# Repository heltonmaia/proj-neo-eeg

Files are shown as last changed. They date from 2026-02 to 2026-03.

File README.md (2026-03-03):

# Neo-EEG Project

Open-source 8-channel EEG acquisition system based on ADS1299 and ESP32.

## Hardware

| Component | Description |
|---|---|
| MCU | ESP32 |
| ADC | ADS1299 (8 channels, 24-bit) |
| Connection | WiFi (UDP) or Bluetooth SPP |
| PCB | PotyEEG v9 |

## Project Structure

```
proj-neo-eeg/
├── docs/
│   ├── datasheets/             # ADS1299 datasheets
│   └── troubleshooting.md      # Troubleshooting guide
│
├── firmware/
│   ├── esp32-wifi/             # ESP32 WiFi firmware
│   │   └── EEG_Poty_ESP32_V10/
│   └── libraries/              # Arduino dependencies
│
├── hardware/
│   └── pcb/
│       └── PotyEEG_v9/         # Eagle PCB files
│
├── software-web/               # Web application (recommended)
│   ├── run.py                  # Cross-platform launcher
│   ├── backend/                # FastAPI server
│   └── frontend/               # React application
│
└── software-processing/        # OpenBCI GUI (legacy)
    └── openbci-gui/
```

## Quick Start (Web Application)

### 1. Flash Firmware

1. Open Arduino IDE
2. Install ESP32 board support
3. Open `firmware/esp32-wifi/EEG_Poty_ESP32_V10/EEG_Poty_ESP32_V10.ino`
4. Select board: ESP32 Dev Module
5. Upload

### 2. Connect to ESP32 WiFi

- **SSID:** `Potyplex-EEG`
- **Password:** `eeg12345`

### 3. Run Web Application

```bash
cd software-web
python run.py
```

Select option `1` to start all services, then open http://localhost:3000

### 4. Use

1. Click **Start** to begin EEG streaming
2. Click **Start Camera** to enable video (optional)
3. Select **Signals** and/or **Video** checkboxes
4. Click **REC** to record

## Features

- Real-time 8-channel EEG visualization
- USB camera streaming
- Recording to CSV (signals) and MP4 (video)
- Offline recording playback
- Dark/Light theme
- Channel selection and zoom controls
- Cross-platform (Linux, Windows, macOS)

## Firmware

The ESP32 firmware streams OpenBCI-compatible packets:

- **Protocol**: OpenBCI binary format (33 bytes)
- **Sample Rate**: 250 Hz
- **Channels**: 8 (ADS1299)
- **Transport**: UDP over WiFi

## Requirements

### Firmware
- Arduino IDE 2.x
- ESP32 Board Support

### Web Application
- Python 3.8+
- Node.js 18+
- OpenCV (for camera)

## License

MIT License

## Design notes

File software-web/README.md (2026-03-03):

# Potyplex EEG - Web Application

Real-time EEG visualization and recording using FastAPI + React.

## Architecture

```
┌─────────────┐     UDP      ┌─────────────┐   WebSocket   ┌─────────────┐
│   ESP32     │─────────────►│   Backend   │──────────────►│  Frontend   │
│  (WiFi AP)  │   12345      │  (FastAPI)  │    8000       │   (React)   │
└─────────────┘              └─────────────┘               └─────────────┘
                                   │
                              ┌────┴────┐
                              │ Camera  │
                              │ (USB)   │
                              └─────────┘
```

## Features

- Real-time 8-channel EEG visualization
- USB camera streaming
- Recording (signals, video, or both)
- Offline recording playback
- Dark/Light theme
- Cross-platform (Linux, Windows, macOS)

## Requirements

- Python 3.8+
- Node.js 18+
- OpenCV (for camera support)
- Modern browser (Chrome, Firefox, Edge)
- UV (optional, recommended for faster dependency management)

## Quick Start

```bash
python run.py
```

This opens an interactive menu to start/stop services, run tests, and more.

**Environment Support:**
- Automatically detects existing UV environments
- Falls back to standard Python venv if UV is not available
- Saves environment configuration in `.env.local.json`

## Manual Start

```bash
# Terminal 1 - Backend (with UV)
cd backend
uv pip install -r requirements.txt
uvicorn server:app --reload --host 0.0.0.0 --port 8000

# Terminal 1 - Backend (without UV)
cd backend
pip install -r requirements.txt
uvicorn server:app --reload --host 0.0.0.0 --port 8000

# Terminal 2 - Frontend
cd frontend
npm install
npm run dev
```

## Usage

1. Connect to ESP32 WiFi: `Potyplex-EEG` (password: `eeg12345`)
2. Run `python run.py` and select "Start All"
3. Open http://localhost:3000
4. Click **Start** to begin EEG streaming
5. Click **Start Camera** to enable video (optional)
6. Select **Signals** and/or **Video** checkboxes
7. Click **REC** to record

## Menu Options

| Key | Action |
|-----|---|
| 1 | Start All (backend + frontend) |
| 2 | Stop All |
| 3 | Restart All |
| 4 | Start Backend only |
| 5 | Stop Backend |
| 6 | Stop Frontend |
| 7 | View Backend Logs |
| 8 | View Frontend Logs |
| 9 | Install Dependencies |
| t | Run Tests |
| s | Setup Python Environment |
| k | Kill Stale Processes |
| 0 | Exit |

## API Endpoints

| Method | Endpoint | Description |
|---|---|---|
| POST | `/start` | Start EEG streaming |
| POST | `/stop` | Stop EEG streaming |
| POST | `/record/start` | Start recording |
| POST | `/record/stop` | Stop recording |
| GET | `/recordings` | List recordings |
| GET | `/recordings/{id}` | Get recording data |
| GET | `/recordings/{id}/video` | Stream video (MP4) |
| DELETE | `/recordings/{id}` | Delete recording |
| GET | `/cameras` | List cameras |
| POST | `/camera/start` | Start camera |
| POST | `/camera/stop` | Stop camera |
| WS | `/ws` | EEG data stream |
| WS | `/ws/camera` | Camera stream |

## Project Structure

```
software-web/
├── run.py             # Cross-platform service manager
├── backend/
│   ├── server.py      # FastAPI server
│   ├── test_server.py # Backend tests (20 tests)
│   ├── requirements.txt
│   └── recordings/    # Saved recordings
├── frontend/
│   ├── src/
│   │   ├── App.jsx
│   │   ├── App.css
│   │   └── components/
│   │       ├── EEGChart.jsx
│   │       ├── CameraPanel.jsx
│   │       └── RecordingsTab.jsx
│   ├── package.json
│   └── vite.config.js
└── README.md
```

## Recording Format

Recordings are stored in `backend/recordings/YYYYMMDD_HHMMSS/`:

- `metadata.json` - Session info (duration, channels, etc.)
- `data.csv` - EEG signals (if recorded)
- `video.mp4` - Camera video (if recorded)

## Testing

Run backend tests:
```bash
python run.py  # then press 't'
```

Or directly:
```bash
cd backend
pytest test_server.py -v
```

## Troubleshooting

**Backend not receiving data:**
- Verify connection to ESP32 WiFi
- Check ESP32 LED is blinking

**Camera not working:**
- Check USB camera is connected
- Verify OpenCV is installed: `pip install opencv-python`

**Services won't start:**
- Press 'k' to kill stale processes
- Check logs with options 7/8

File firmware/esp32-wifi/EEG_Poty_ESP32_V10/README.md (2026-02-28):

# ESP32 WiFi Firmware (Access Point Mode)

Versão modificada do firmware para usar WiFi UDP ao invés de Bluetooth SPP. O ESP32 cria sua própria rede WiFi (Access Point).

## Arquitetura

```
                    ┌──────────────────────┐
                    │   Potyplex EEG       │
[Computador] ◄─────►│   Access Point       │
     ou             │                      │
[Celular]    ◄─UDP─►│   SSID: Potyplex-EEG │
                    │   IP: 192.168.4.1    │
                    │   Port: 12345        │
                    └──────────────────────┘
```

**Conecte diretamente no EEG - não precisa de roteador!**

## Configuração Padrão

| Parâmetro | Valor |
|---|---|
| SSID | `Potyplex-EEG` |
| Senha | `eeg12345` |
| IP do ESP32 | `192.168.4.1` |
| Porta UDP | `12345` |

---

## Instalação

### 1. Instalar Bibliotecas (Arduino IDE)

Vá em **Sketch → Include Library → Manage Libraries** e instale:
- `Adafruit MPU6050`
- `Adafruit BusIO`
- `Adafruit Unified Sensor`

### 2. Configurar (opcional)

Edite `EEG_Poty_ESP32_Library_Definitions.h`:

```c
#define AP_SSID     "Potyplex-EEG"    // Nome da rede
#define AP_PASSWORD "eeg12345"         // Senha (min 8 chars)
#define AP_CHANNEL  1                  // Canal WiFi (1-13)
#define UDP_PORT    12345              // Porta UDP
```

### 3. Compilar e Upload

1. Abra Arduino IDE
2. Selecione placa: **ESP32 Dev Module**
3. Abra `EEG_Poty_ESP32_V10.ino`
4. Clique em Upload

### 4. Verificar

Abra Serial Monitor (115200 baud):

```
===========================================
  Potyplex EEG - WiFi Access Point Mode
===========================================
Creating network: Potyplex-EEG
[OK] Access Point started!
SSID: Potyplex-EEG
Password: eeg12345
ESP32 IP: 192.168.4.1
UDP Port: 12345
[OK] UDP server started
===========================================
  1. Connect to WiFi: Potyplex-EEG
  2. Send 'b' to 192.168.4.1:12345
===========================================
```

---

## Conectando e Recebendo Dados

### Linux - Teste Rápido

```bash
# 1. Conecte no WiFi "Potyplex-EEG" (senha: eeg12345)

# 2. Enviar comando e receber dados
nc -u 192.168.4.1 12345
# Digite 'b' + Enter para iniciar streaming
# Digite 's' + Enter para parar
```

### Celular

Use um app UDP (ex: "UDP Terminal" no Android):
1. Conecte no WiFi `Potyplex-EEG`
2. Configure IP: `192.168.4.1`, Port: `12345`
3. Envie `b` para iniciar

### Python - Cliente Completo

```python
#!/usr/bin/env python3
"""
Cliente para Potyplex EEG WiFi
"""
import socket

ESP32_IP = "192.168.4.1"
UDP_PORT = 12345

# Criar socket UDP
sock = socket.socket(socket.AF_INET, socket.SOCK_DGRAM)
sock.settimeout(5.0)
sock.bind(('0.0.0.0', 0))  # Bind em porta aleatória

# Iniciar streaming
sock.sendto(b'b', (ESP32_IP, UDP_PORT))
print("Streaming iniciado!")

# Receber dados
while True:
    try:
        data, addr = sock.recvfrom(33)

        if len(data) == 33 and data[0] == 0xA0 and data[32] == 0xC0:
            sample_num = data[1]

            # Extrair 8 canais (24 bits cada, signed)
            channels = []
            for ch in range(8):
                offset = 2 + ch * 3
                raw = (data[offset] << 16) | (data[offset+1] << 8) | data[offset+2]
                if raw & 0x800000:  # Negativo (complemento de 2)
                    raw -= 0x1000000
                channels.append(raw)

            print(f"Sample {sample_num:3d}: CH1={channels[0]:8d} CH2={channels[1]:8d}")

    except socket.timeout:
        print("Timeout")
        break
    except KeyboardInterrupt:
        sock.sendto(b's', (ESP32_IP, UDP_PORT))
        print("Streaming parado")
        break

sock.close()
```

---

## Protocolo de Dados

Cada pacote tem **33 bytes**:

| Offset | Tamanho | Descrição |
|---|---|---|
| 0 | 1 | Header: `0xA0` |
| 1 | 1 | Contador (0-255) |
| 2-25 | 24 | 8 canais EEG (3 bytes cada, 24-bit signed) |
| 26-31 | 6 | Acelerômetro (3 eixos, 2 bytes cada) |
| 32 | 1 | Footer: `0xC0` |

**Taxa:** 250 amostras/segundo

---

## Comandos OpenBCI

| Comando | Descrição |
|---|---|
| `b` | Iniciar streaming |
| `s` | Parar streaming |
| `v` | Soft reset (mostra info) |
| `?` | Query registradores |
| `d` | Configurações default |
| `1-8` | Desligar canal 1-8 |
| `!@#$%^&*` | Ligar canal 1-8 |

---

## LED Status

| Padrão | Significado |
|---|---|
| 3 piscadas rápidas | AP iniciado OK |
| LED fixo | Erro ao criar AP |
| Piscando durante streaming | Enviando dados |

---

## Arquivos

| Arquivo | Descrição |
|---|---|
| `EEG_Poty_ESP32_V10.ino` | Sketch principal |
| `EEG_Poty_ESP32_Library_Definitions.h` | Configurações WiFi/hardware |
| `EEG_Poty_ESP32_Library.h` | Header da biblioteca |
| `EEG_Poty_ESP32_Library.cpp` | Implementação |

---

## Troubleshooting

### Não encontra a rede WiFi
- Verifique Serial Monitor para erros
- Tente mudar `AP_CHANNEL` para outro canal (1-13)

### Não recebe dados
- Verifique se está conectado na rede `Potyplex-EEG`
- Confirme IP `192.168.4.1` e porta `12345`
- Envie `b` para iniciar streaming

### Cliente desconecta
- Timeout padrão é 30 segundos sem comandos
- Envie qualquer comando como keepalive
- Ou aumente `CLIENT_TIMEOUT_MS` em `_Definitions.h`

---

## Referências

- [ESP32 WiFi API](https://docs.espressif.com/projects/esp-idf/en/latest/esp32/api-reference/network/esp_wifi.html)
- [OpenBCI Protocol](https://docs.openbci.com/Cyton/CytonSDK/)

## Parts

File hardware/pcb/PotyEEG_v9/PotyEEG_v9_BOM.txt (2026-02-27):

Partlist exported from D:/Users/WinU31/Documents/Projects/PotyEEG/Project/Hardware/PotyEEG_v9.sch at 29/10/2021 20:17

Part Value                                                              Device                                                             Package                           Description                                                   
C1   0.1uF                                                              C-EUC0805K                                                         C0805K                            CAPACITOR, European symbol                                    
C2   10uF                                                               C-EUC0805K                                                         C0805K                            CAPACITOR, European symbol                                    
C3   10uF                                                               C-EUC0805K                                                         C0805K                            CAPACITOR, European symbol                                    
C4   .1uF                                                               C-EUC0805K                                                         C0805K                            CAPACITOR, European symbol                                    
C5   1uF                                                                C-EUC0805K                                                         C0805K                            CAPACITOR, European symbol                                    
C6   100uF                                                              C-EUC0805K                                                         C0805K                            CAPACITOR, European symbol                                    
C7   1uF                                                                C-EUC0805K                                                         C0805K                            CAPACITOR, European symbol                                    
C8   2.2uF                                                              C-EUC0805K                                                         C0805K                            CAPACITOR, European symbol                                    
C9   2.2uF                                                              C-EUC0805K                                                         C0805K                            CAPACITOR, European symbol                                    
C10  10uF                                                               C-EUC0805K                                                         C0805K                            CAPACITOR, European symbol                                    
C11  10uF                                                               C-EUC0805K                                                         C0805K                            CAPACITOR, European symbol                                    
C12  0.01uF                                                             C-EUC0805K                                                         C0805K                            CAPACITOR, European symbol                                    
C13  2.2uF                                                              C-EUC0805K                                                         C0805K                            CAPACITOR, European symbol                                    
C14  10uF                                                               C-EUC0805K                                                         C0805K                            CAPACITOR, European symbol                                    
C15  2.2uF                                                              C-EUC0805K                                                         C0805K                            CAPACITOR, European symbol                                    
C16  10uF                                                               C-EUC0805K                                                         C0805K                            CAPACITOR, European symbol                                    
C17  10uF                                                               C-EUC0603                                                          C0603                             CAPACITOR, European symbol                                    
C18  10uF                                                               C-EUC0603                                                          C0603                             CAPACITOR, European symbol                                    
C19  10uF                                                               C-EUC0805K                                                         C0805K                            CAPACITOR, European symbol                                    
C20  10uF                                                               C-EUC0805K                                                         C0805K                            CAPACITOR, European symbol                                    
C21  10uF                                                               C-EUC0805K                                                         C0805K                            CAPACITOR, European symbol                                    
C25  1000pF                                                             C-EUC0603                                                          C0603                             CAPACITOR, European symbol                                    
C26  1000pF                                                             C-EUC0603                                                          C0603                             CAPACITOR, European symbol                                    
C27  1000pF                                                             C-EUC0603                                                          C0603                             CAPACITOR, European symbol                                    
C28  1000pF                                                             C-EUC0603                                                          C0603                             CAPACITOR, European symbol                                    
C29  1000pF                                                             C-EUC0603                                                          C0603                             CAPACITOR, European symbol                                    
C30  1000pF                                                             C-EUC0603                                                          C0603                             CAPACITOR, European symbol                                    
C31  1000pF                                                             C-EUC0603                                                          C0603                             CAPACITOR, European symbol                                    
C32  1000pF                                                             C-EUC0603                                                          C0603                             CAPACITOR, European symbol                                    
LED1                                                                    LEDSML0805                                                         SML0805                           LED                                                           
LED2                                                                    LEDSML0805                                                         SML0805                           LED                                                           
R1   2,2K                                                               R-EU_R0603                                                         R0603                             RESISTOR, European symbol                                     
R2   2,2K                                                               R-EU_R0603                                                         R0603                             RESISTOR, European symbol                                     
R3   2,2K                                                               R-EU_R0603                                                         R0603                             RESISTOR, European symbol                                     
R9   2,2K                                                               R-EU_R0603                                                         R0603                             RESISTOR, European symbol                                     
R10  2,2K                                                               R-EU_R0603                                                         R0603                             RESISTOR, European symbol                                     
R11  2,2K                                                               R-EU_R0603                                                         R0603                             RESISTOR, European symbol                                     
R12  2,2K                                                               R-EU_R0603                                                         R0603                             RESISTOR, European symbol                                     
R13  2,2K                                                               R-EU_R0603                                                         R0603                             RESISTOR, European symbol                                     
R14  2,2K                                                               R-EU_R0603                                                         R0603                             RESISTOR, European symbol                                     
R15  2,2K                                                               R-EU_R0603                                                         R0603                             RESISTOR, European symbol                                     
R16  2,2K                                                               R-EU_R0603                                                         R0603                             RESISTOR, European symbol                                     
S1   SKHMPSE010                                                         SKHMPSE010                                                         SKHMPXE010                        6.2 X 6.5mm TACT Switch (SMD)                                 
U1   ADS1299IPAG                                                        ADS1299IPAG                                                        PAG64_TEX                                                                                       
U2   MICROCHIP_MCP1754T-3302E-OTMICROCHIP_MCP1754T-3302E-OT_0_1         MICROCHIP_MCP1754T-3302E-OTMICROCHIP_MCP1754T-3302E-OT_0_1         MICROCHIP_MCP1754T-3302E-OT_1     MCHP-MCP1754-SOT-23-5                                         
U3   TEXAS_INSTRUMENTS_LM2664M6-NOPBTEXAS_INSTRUMENTS_LM2664M6-NOPB_0_2 TEXAS_INSTRUMENTS_LM2664M6-NOPBTEXAS_INSTRUMENTS_LM2664M6-NOPB_0_2 TEXAS_INSTRUMENTS_LM2664M6-NOPB_2 PM-CHP-LM2664M6-6                                             
U4   TPS72325DBVTDBV5_TEX-M                                             TPS72325DBVTDBV5_TEX-M                                             DBV5_TEX-M                                                                                      
U5   TLV70012DDCRDDC5-M                                                 TLV70012DDCRDDC5-M                                                 DDC5-M                                                                                          
U6   DFR0478                                                            DFR0478                                                            FIREBEETLE_ESP32                  Development Boards & Kits - Wireless FireBeetle ESP32 IOT MCU 
U7   TPD4E1B06DRLR                                                      TPD4E1B06DRLR                                                      SOP50P160X60-6N                   Bidirectional Quad-Channel High-Speed ESD Protection Device   
U8   TPD4E1B06DRLR                                                      TPD4E1B06DRLR                                                      SOP50P160X60-6N                   Bidirectional Quad-Channel High-Speed ESD Protection Device   
X3   53261-14                                                           53261-14                                                           53261-14                          CONNECTOR

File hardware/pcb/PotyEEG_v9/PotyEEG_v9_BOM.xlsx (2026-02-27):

Part | Value | Device | Package | Description | Price
C1 | 0.1uF | C-EUC0805K | C0805K | CAPACITOR, | 0.4 | https://br.mouser.com/ProductDetail/Vishay-Vitramon/VJ0805V104MXQCW1BC?qs=PU%2FMJZm1WmnVlMGMvnOOYg%3D%3D
C2 | 10uF | C-EUC0805K | C0805K | CAPACITOR, | 0.7 | https://br.mouser.com/ProductDetail/Vishay-Vitramon/VJ0805G106KXYTW1BC?qs=cB7NDbAiiddiblHyPR7ZhA%3D%3D
C3 | 10uF | C-EUC0805K | C0805K | CAPACITOR, | 0.7 | https://br.mouser.com/ProductDetail/Vishay-Vitramon/VJ0805G106KXYTW1BC?qs=cB7NDbAiiddiblHyPR7ZhA%3D%3D
C4 | .1uF | C-EUC0805K | C0805K | CAPACITOR, | 0.4 | https://br.mouser.com/ProductDetail/Vishay-Vitramon/VJ0805V104MXQCW1BC?qs=PU%2FMJZm1WmnVlMGMvnOOYg%3D%3D
C5 | 1uF | C-EUC0805K | C0805K | CAPACITOR, | 0.23 | https://br.mouser.com/ProductDetail/Vishay-Vitramon/VJ0805Y105KXQTW1BC?qs=F2lBERbFaaHnNHh23%2Flzkg%3D%3D
C6 | 100uF | C-EUC0805K | C0805K | CAPACITOR, | 1.21 | https://br.mouser.com/ProductDetail/Murata-Electronics/GRM21BR60G107ME15L?qs=K0Sa7bCb58Jf5FAKg556bA%3D%3D
C7 | 1uF | C-EUC0805K | C0805K | CAPACITOR, | 0.23 | https://br.mouser.com/ProductDetail/Vishay-Vitramon/VJ0805Y105KXQTW1BC?qs=F2lBERbFaaHnNHh23%2Flzkg%3D%3D
C8 | 2.2uF | C-EUC0805K | C0805K | CAPACITOR, | 0.45 | https://br.mouser.com/ProductDetail/Vishay-Vitramon/VJ0805G225MXQTW1BC?qs=iFBwIILKtq5v%252ByyKF5EfrQ%3D%3D
C9 | 2.2uF | C-EUC0805K | C0805K | CAPACITOR, | 0.45 | https://br.mouser.com/ProductDetail/Vishay-Vitramon/VJ0805G225MXQTW1BC?qs=iFBwIILKtq5v%252ByyKF5EfrQ%3D%3D
C10 | 10uF | C-EUC0805K | C0805K | CAPACITOR, | 0.7 | https://br.mouser.com/ProductDetail/Vishay-Vitramon/VJ0805G106KXYTW1BC?qs=cB7NDbAiiddiblHyPR7ZhA%3D%3D
C11 | 10uF | C-EUC0805K | C0805K | CAPACITOR, | 0.7 | https://br.mouser.com/ProductDetail/Vishay-Vitramon/VJ0805G106KXYTW1BC?qs=cB7NDbAiiddiblHyPR7ZhA%3D%3D
C12 | 0.01uF | C-EUC0805K | C0805K | CAPACITOR, | 0.28 | https://br.mouser.com/ProductDetail/Vishay-Vitramon/VJ0805V103MXQCW1BC?qs=PU%2FMJZm1WmlnHIvGGoxPxg%3D%3D
C13 | 2.2uF | C-EUC0805K | C0805K | CAPACITOR, | 0.45 | https://br.mouser.com/ProductDetail/Vishay-Vitramon/VJ0805G225MXQTW1BC?qs=iFBwIILKtq5v%252ByyKF5EfrQ%3D%3D
C14 | 10uF | C-EUC0805K | C0805K | CAPACITOR, | 0.7 | https://br.mouser.com/ProductDetail/Vishay-Vitramon/VJ0805G106KXYTW1BC?qs=cB7NDbAiiddiblHyPR7ZhA%3D%3D
C15 | 2.2uF | C-EUC0805K | C0805K | CAPACITOR, | 0.45 | https://br.mouser.com/ProductDetail/Vishay-Vitramon/VJ0805G225MXQTW1BC?qs=iFBwIILKtq5v%252ByyKF5EfrQ%3D%3D
C16 | 10uF | C-EUC0805K | C0805K | CAPACITOR, | 0.7 | https://br.mouser.com/ProductDetail/Vishay-Vitramon/VJ0805G106KXYTW1BC?qs=cB7NDbAiiddiblHyPR7ZhA%3D%3D
C17 | 10uF | C-EUC0603 | C0603 | CAPACITOR, | 0.7 | https://br.mouser.com/ProductDetail/Vishay-Vitramon/VJ0805G106KXYTW1BC?qs=cB7NDbAiiddiblHyPR7ZhA%3D%3D
C18 | 10uF | C-EUC0603 | C0603 | CAPACITOR, | 0.7 | https://br.mouser.com/ProductDetail/Vishay-Vitramon/VJ0805G106KXYTW1BC?qs=cB7NDbAiiddiblHyPR7ZhA%3D%3D
C19 | 10uF | C-EUC0805K | C0805K | CAPACITOR, | 0.7 | https://br.mouser.com/ProductDetail/Vishay-Vitramon/VJ0805G106KXYTW1BC?qs=cB7NDbAiiddiblHyPR7ZhA%3D%3D
C20 | 10uF | C-EUC0805K | C0805K | CAPACITOR, | 0.7 | https://br.mouser.com/ProductDetail/Vishay-Vitramon/VJ0805G106KXYTW1BC?qs=cB7NDbAiiddiblHyPR7ZhA%3D%3D
C21 | 10uF | C-EUC0805K | C0805K | CAPACITOR, | 0.7 | https://br.mouser.com/ProductDetail/Vishay-Vitramon/VJ0805G106KXYTW1BC?qs=cB7NDbAiiddiblHyPR7ZhA%3D%3D
C25 | 1000pF | C-EUC0603 | C0603 | CAPACITOR, | 0.36 | https://br.mouser.com/ProductDetail/Vishay-Vitramon/VJ0603A102JXQCW1BC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
C26 | 1000pF | C-EUC0603 | C0603 | CAPACITOR, | 0.36 | https://br.mouser.com/ProductDetail/Vishay-Vitramon/VJ0603A102JXQCW1BC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
C27 | 1000pF | C-EUC0603 | C0603 | CAPACITOR, | 0.36 | https://br.mouser.com/ProductDetail/Vishay-Vitramon/VJ0603A102JXQCW1BC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
C28 | 1000pF | C-EUC0603 | C0603 | CAPACITOR, | 0.36 | https://br.mouser.com/ProductDetail/Vishay-Vitramon/VJ0603A102JXQCW1BC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
C29 | 1000pF | C-EUC0603 | C0603 | CAPACITOR, | 0.36 | https://br.mouser.com/ProductDetail/Vishay-Vitramon/VJ0603A102JXQCW1BC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
C30 | 1000pF | C-EUC0603 | C0603 | CAPACITOR, | 0.36 | https://br.mouser.com/ProductDetail/Vishay-Vitramon/VJ0603A102JXQCW1BC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
C31 | 1000pF | C-EUC0603 | C0603 | CAPACITOR, | 0.36 | https://br.mouser.com/ProductDetail/Vishay-Vitramon/VJ0603A102JXQCW1BC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
C32 | 1000pF | C-EUC0603 | C0603 | CAPACITOR, | 0.36 | https://br.mouser.com/ProductDetail/Vishay-Vitramon/VJ0603A102JXQCW1BC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
LED1 | LEDSML0805 | SML0805 | LED |  | 0.39 | https://br.mouser.com/ProductDetail/Vishay-Semiconductors/VLMB1300-GS08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
LED2 | LEDSML0805 | SML0805 | LED |  | 0.49 | https://br.mouser.com/ProductDetail/78-VLMTG1300-GS08
R1 | 2,2K | R-EU_R0603 | R0603 | RESISTOR, | 0.1 | https://br.mouser.com/ProductDetail/Vishay-Dale/CRCW06032K20FKEA?qs=wckIcdUuIXiMEbhHncbunA%3D%3D
R2 | 2,2K | R-EU_R0603 | R0603 | RESISTOR, | 0.1 | https://br.mouser.com/ProductDetail/Vishay-Dale/CRCW06032K20FKEA?qs=wckIcdUuIXiMEbhHncbunA%3D%3D
R3 | 2,2K | R-EU_R0603 | R0603 | RESISTOR, | 0.1 | https://br.mouser.com/ProductDetail/Vishay-Dale/CRCW06032K20FKEA?qs=wckIcdUuIXiMEbhHncbunA%3D%3D
R9 | 2,2K | R-EU_R0603 | R0603 | RESISTOR, | 0.1 | https://br.mouser.com/ProductDetail/Vishay-Dale/CRCW06032K20FKEA?qs=wckIcdUuIXiMEbhHncbunA%3D%3D
R10 | 2,2K | R-EU_R0603 | R0603 | RESISTOR, | 0.1 | https://br.mouser.com/ProductDetail/Vishay-Dale/CRCW06032K20FKEA?qs=wckIcdUuIXiMEbhHncbunA%3D%3D
R11 | 2,2K | R-EU_R0603 | R0603 | RESISTOR, | 0.1 | https://br.mouser.com/ProductDetail/Vishay-Dale/CRCW06032K20FKEA?qs=wckIcdUuIXiMEbhHncbunA%3D%3D
R12 | 2,2K | R-EU_R0603 | R0603 | RESISTOR, | 0.1 | https://br.mouser.com/ProductDetail/Vishay-Dale/CRCW06032K20FKEA?qs=wckIcdUuIXiMEbhHncbunA%3D%3D
R13 | 2,2K | R-EU_R0603 | R0603 | RESISTOR, | 0.1 | https://br.mouser.com/ProductDetail/Vishay-Dale/CRCW06032K20FKEA?qs=wckIcdUuIXiMEbhHncbunA%3D%3D
R14 | 2,2K | R-EU_R0603 | R0603 | RESISTOR, | 0.1 | https://br.mouser.com/ProductDetail/Vishay-Dale/CRCW06032K20FKEA?qs=wckIcdUuIXiMEbhHncbunA%3D%3D
R15 | 2,2K | R-EU_R0603 | R0603 | RESISTOR, | 0.1 | https://br.mouser.com/ProductDetail/Vishay-Dale/CRCW06032K20FKEA?qs=wckIcdUuIXiMEbhHncbunA%3D%3D
R16 | 2,2K | R-EU_R0603 | R0603 | RESISTOR, | 0.1 | https://br.mouser.com/ProductDetail/Vishay-Dale/CRCW06032K20FKEA?qs=wckIcdUuIXiMEbhHncbunA%3D%3D
S1 | SKHMPSE010 | SKHMPSE010 | SKHMPXE010 | 6.2 | 0.42 | https://br.mouser.com/ProductDetail/688-SKHMQKE010
U1 | ADS1299IPAG | ADS1299IPAG |  |  | 68.68 | https://br.mouser.com/ProductDetail/Texas-Instruments/ADS1299IPAG?qs=g9Q%2FF7kJgMyNB%2Fl7Pgr%252B%252BA%3D%3D
U2 | MCP1754T |  |  |  | 0.49 | https://br.mouser.com/ProductDetail/Microchip-Technology/MCP1754T-3302E-OT?qs=3wWX5hyYeeTLQCcLPl0MGw%3D%3D
U3 | LM2664M6 |  |  |  | 0.92 | https://br.mouser.com/ProductDetail/Texas-Instruments/LM2664M6-NOPB?qs=X1J7HmVL2ZFqN%2Fb7EAhtIA%3D%3D
U4 | TPS72325 |  |  |  | 3.14 | https://br.mouser.com/ProductDetail/Texas-Instruments/TPS72325DBVR?qs=6zVL%252ByCp0mrCtYCk6%2F08lw%3D%3D
U5 | TLV70012 |  |  |  | 0.84 | https://br.mouser.com/ProductDetail/Texas-Instruments/TLV70025QDDCRQ1?qs=NiBvnJE4bX1tmxoZbCukhA%3D%3D
U6 | ESP32 | DFR0478 | FIREBEETLE_ESP32 | Development | 19 | https://br.mouser.com/ProductDetail/DFRobot/DFR0478
U7 | TPD4E1B06DRLR | TPD4E1B06DRLR | SOP50P160X60-6N |  | 0.66 | https://br.mouser.com/ProductDetail/Texas-Instruments/TPD4E1B06DCKR?qs=FBI%252BX3tnPf1Bt8uBkGhcNg%3D%3D
U8 | TPD4E1B06DRLR | TPD4E1B06DRLR | SOP50P160X60-6N |  | 0.66 | https://br.mouser.com/ProductDetail/Texas-Instruments/TPD4E1B06DCKR?qs=FBI%252BX3tnPf1Bt8uBkGhcNg%3D%3D
X3 | 53261-1471 | 53261-14 | 53261-14 | CONNECTOR MOLEX | 1.33 | https://br.mouser.com/ProductDetail/Molex/53261-1471?qs=%252B72YyncTwW92HgDz7vQRIQ%3D%3D
 |  |  |  |  | 113.25

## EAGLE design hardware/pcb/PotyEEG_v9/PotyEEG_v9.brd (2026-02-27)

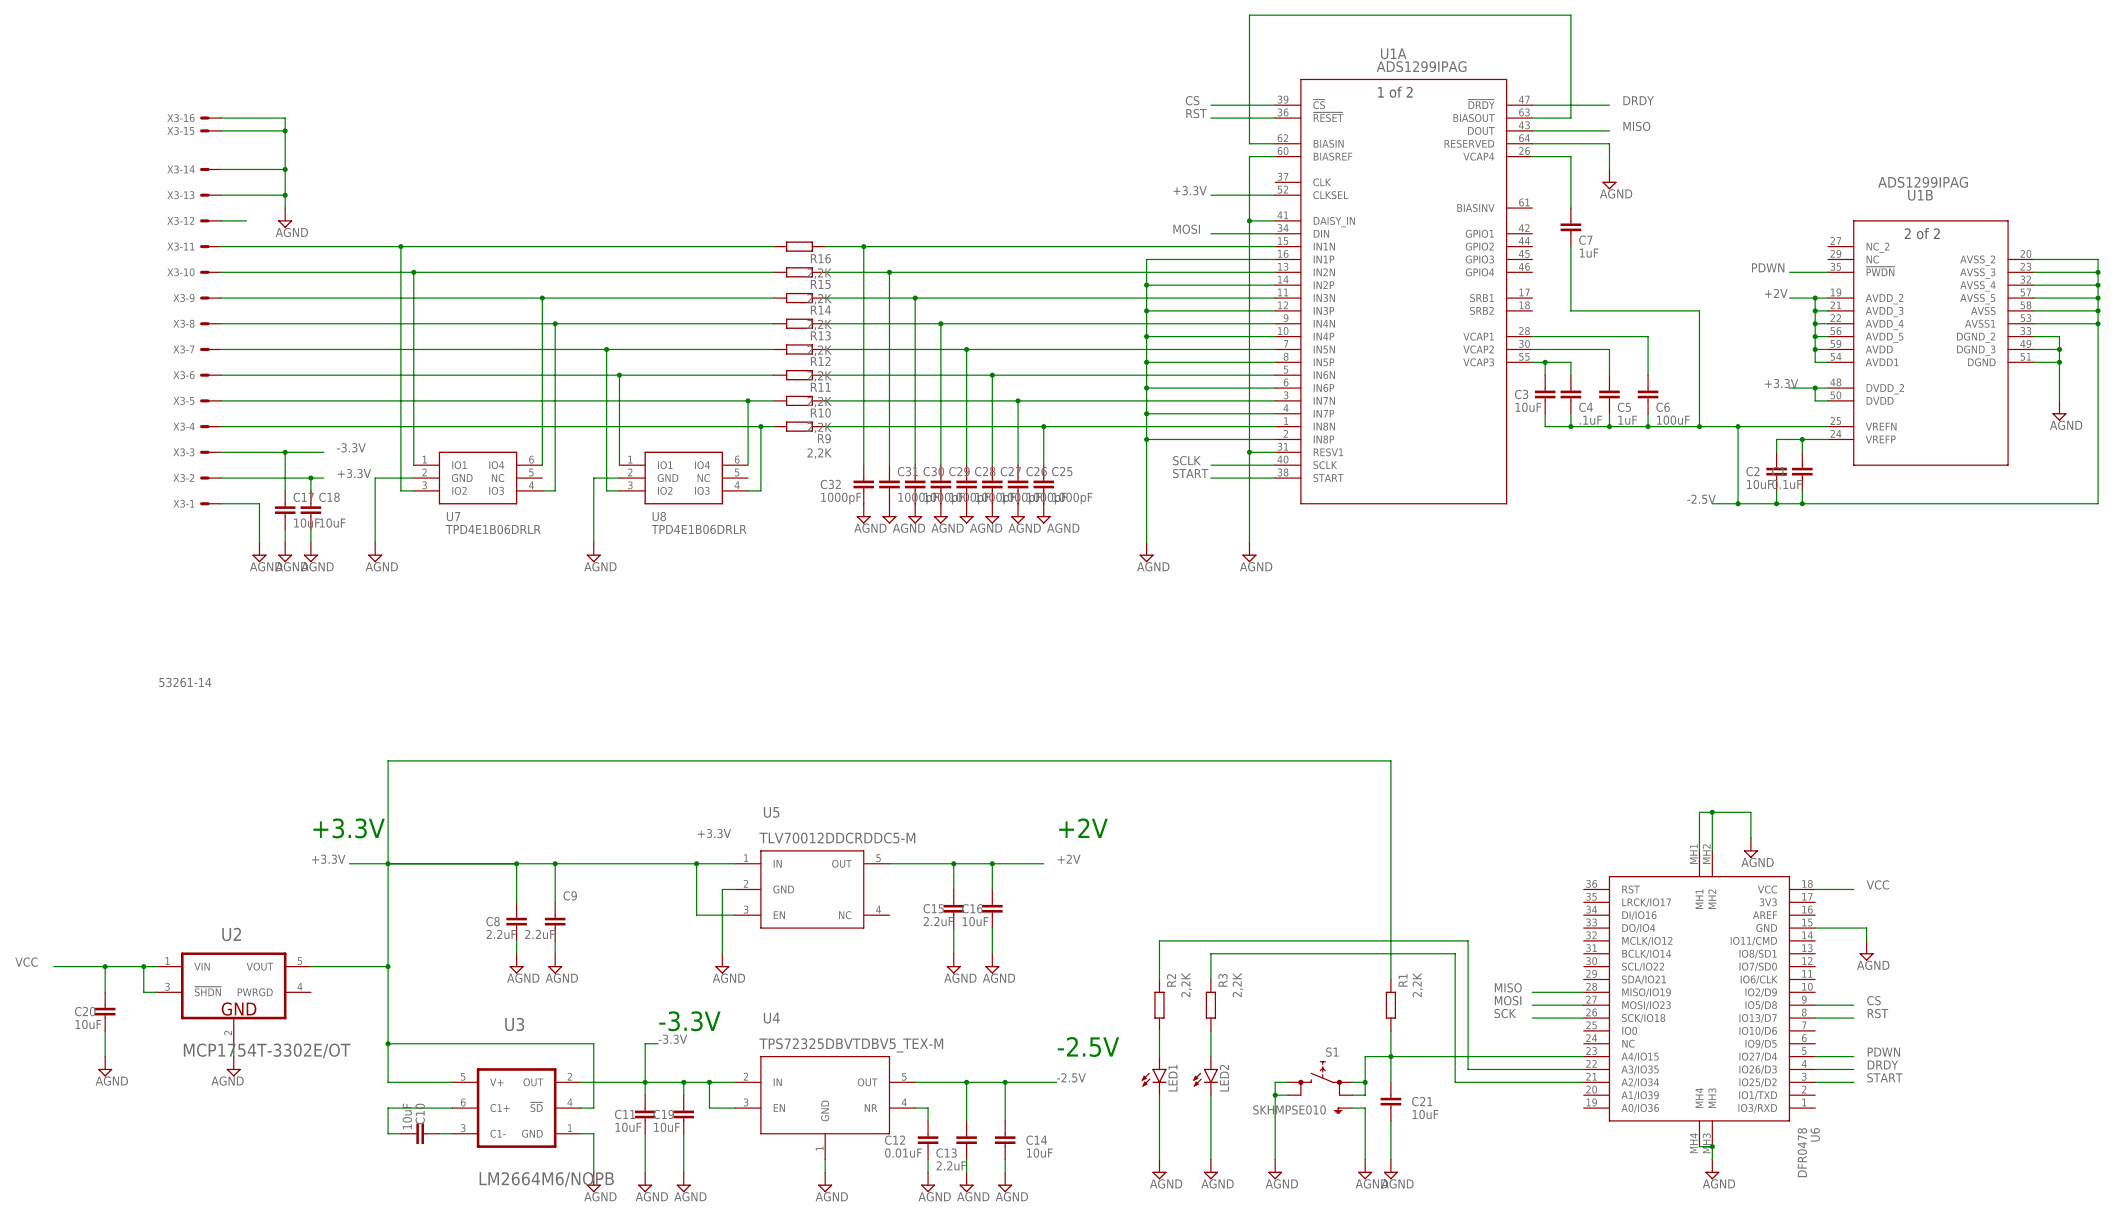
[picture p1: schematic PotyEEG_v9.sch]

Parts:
C1: 0.1uF; C0805K
C2, C3, C10, C11, C14, C16, C19, C20, C21: 10uF; C0805K
C4: .1uF; C0805K
C5, C7: 1uF; C0805K
C6: 100uF; C0805K
C8, C9, C13, C15: 2.2uF; C0805K
C12: 0.01uF; C0805K
C17, C18: 10uF; C0603
C25, C26, C27, C28, C29, C30, C31, C32: 1000pF; C0603
LED1, LED2: LEDSML0805; SML0805
R1, R2, R3, R9, R10, R11, R12, R13, R14, R15, R16: 2,2K; R0603
S1: SKHMPSE010; SKHMPXE010
U1: ADS1299IPAG; PAG64_TEX
U2: MICROCHIP_MCP1754T-3302E-OTMICROCHIP_MCP1754T-330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; MICROCHIP_MCP1754T-3302E-OT_1
U3: TEXAS_INSTRUMENTS_LM2664M6-NOPBTEXAS_INSTRUMENTS_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; TEXAS_INSTRUMENTS_LM2664M6-NOPB_2
U4: TPS72325DBVTDBV5_TEX-M; DBV5_TEX-M
U5: TLV70012DDCRDDC5-M; DDC5-M
U6: DFR0478; FIREBEETLE_ESP32
U7, U8: TPD4E1B06DRLR; SOP50P160X60-6N
X3: 53261-14

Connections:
+2V: C15.1, C16.1, U1.19 (AVDD_2), U1.21 (AVDD_3), U1.22 (AVDD_4), U1.54 (AVDD1), U1.56 (AVDD_5), U1.59 (AVDD), U5.5 (OUT)
+3.3V: C8.1, C9.1, C18.1, R1.1, U1.48 (DVDD_2), U1.50 (DVDD), U1.52 (CLKSEL), U2.5 (VOUT), U3.4 (!SD!), U3.5 (V+), U5.1 (IN), U5.3 (EN), X3.2
-2.5V: C1.2, C2.2, C3.2, C4.2, C5.2, C6.2, C7.2, C13.1, C14.1, U1.20 (AVSS_2), U1.23 (AVSS_3), U1.25 (VREFN), U1.32 (AVSS_4), U1.53 (AVSS1), U1.57 (AVSS_5), U1.58 (AVSS), U4.5 (OUT)
-3.3V: C11.1, C17.1, C19.1, U3.2 (OUT), U4.2 (IN), U4.3 (EN), X3.3
CS: U1.39 (!CS), U6.9 (IO5/D8)
DRDY: U1.47 (!DRDY), U6.4 (IO26/D3)
GND: C8.2, C9.2, C11.2, C12.2, C13.2, C14.2, C15.2, C16.2, C17.2, C18.2, C19.2, C20.2, C21.2, C25.2, C26.2, C27.2, C28.2, C29.2, C30.2, C31.2, C32.2, LED1.C, LED2.C, S1.3 (2.1), S1.4 (2.2), S1.5 (SH), U1.2 (IN8P), U1.4 (IN7P), U1.6 (IN6P), U1.8 (IN5P), U1.10 (IN4P), U1.12 (IN3P), U1.14 (IN2P), U1.16 (IN1P), U1.31 (RESV1), U1.33 (DGND_2), U1.41 (DAISY_IN), U1.49 (DGND_3), U1.51 (DGND), U1.60 (BIASREF), U1.64 (RESERVED), U2.2 (GND), U3.1 (GND), U4.1 (GND), U5.2 (GND), U6.15 (GND), U6.MH1, U6.MH2, U6.MH3, U6.MH4, U7.2 (GND), U8.2 (GND), X3.1, X3.13, X3.14, X3.S1, X3.S2
MISO: U1.43 (DOUT), U6.28 (MISO/IO19)
MOSI: U1.34 (DIN), U6.27 (MOSI/IO23)
unnamed: C1.1, C2.1, U1.24 (VREFP)
unnamed: C3.1, C4.1, U1.55 (VCAP3)
unnamed: C5.1, U1.30 (VCAP2)
unnamed: C6.1, U1.28 (VCAP1)
unnamed: C7.1, U1.26 (VCAP4)
unnamed: C21.1, R1.2, S1.1 (1.1), S1.2 (1.2), U6.23 (A4/IO15)
unnamed: R9.2, U8.4 (IO3), X3.4
unnamed: R10.2, U8.6 (IO4), X3.5
unnamed: R11.2, U8.1 (IO1), X3.6
unnamed: R2.1, U6.22 (A3/IO35)
unnamed: R12.2, U8.3 (IO2), X3.7
unnamed: C12.1, U4.4 (NR)
unnamed: R13.2, U7.4 (IO3), X3.8
unnamed: C10.1, U3.3 (C1-)
unnamed: C10.2, U3.6 (C1+)
unnamed: R14.2, U7.6 (IO4), X3.9
unnamed: LED1.A, R2.2
unnamed: R15.2, U7.1 (IO1), X3.10
unnamed: U1.62 (BIASIN), U1.63 (BIASOUT)
unnamed: R3.1, U6.21 (A2/IO34)
unnamed: LED2.A, R3.2
unnamed: C25.1, R9.1, U1.1 (IN8N)
unnamed: C26.1, R10.1, U1.3 (IN7N)
unnamed: C27.1, R11.1, U1.5 (IN6N)
unnamed: C28.1, R12.1, U1.7 (IN5N)
unnamed: C29.1, R13.1, U1.9 (IN4N)
unnamed: C30.1, R14.1, U1.11 (IN3N)
unnamed: C31.1, R15.1, U1.13 (IN2N)
unnamed: C32.1, R16.1, U1.15 (IN1N)
unnamed: R16.2, U7.3 (IO2), X3.11
PDWN: U1.35 (!PWDN), U6.5 (IO27/D4)
RST: U1.36 (!RESET), U6.8 (IO13/D7)
SCK: U6.26 (SCK/IO18)
SCLK: U1.40 (SCLK)
START: U1.38 (START), U6.3 (IO25/D2)
VCC: C20.1, U2.1 (VIN), U2.3 (!SHDN!), U6.18 (VCC)

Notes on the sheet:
+3.3V
-3.3V
-2.5V
+2V

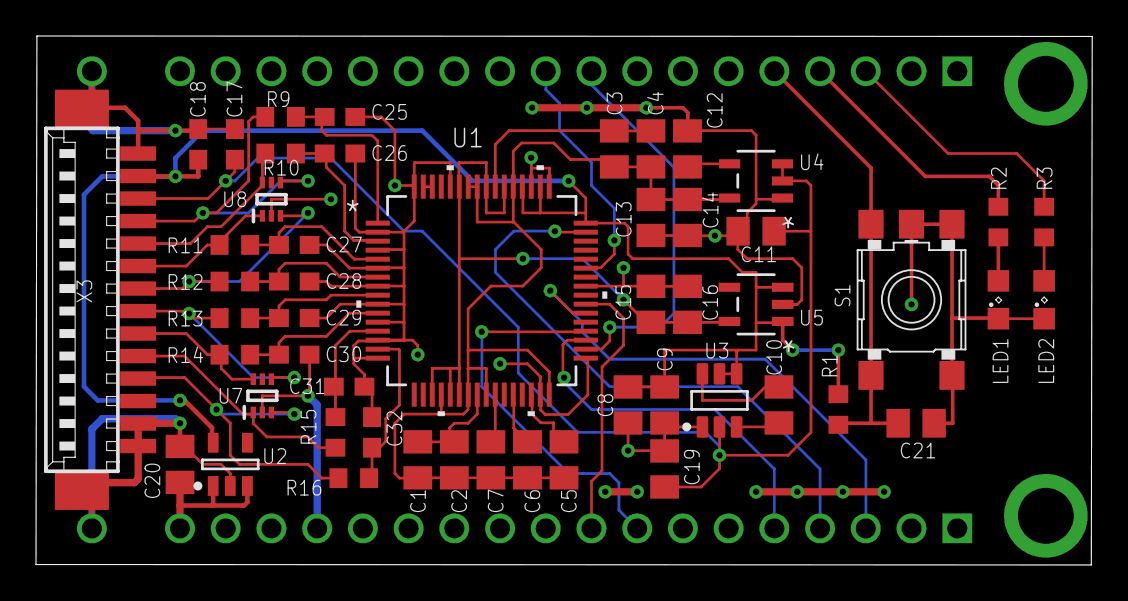
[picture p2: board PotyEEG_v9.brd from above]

Board: 2 copper layers, 58.7 x 29.4 mm, 52 parts (1 on the bottom side), 43 nets.

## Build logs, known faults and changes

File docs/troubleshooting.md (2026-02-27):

# Troubleshooting

## Bluetooth Connection Issues

### Device not found
```bash
# Check if device is paired
bluetoothctl devices

# If not listed, pair it:
bluetoothctl
> scan on
> pair 0C:DC:7E:8E:30:8E
> trust 0C:DC:7E:8E:30:8E
> exit
```

### rfcomm port not created
```bash
# Check if port exists
ls -la /dev/rfcomm*

# Release and recreate
sudo rfcomm release 0
sudo rfcomm bind 0 0C:DC:7E:8E:30:8E
```

### Permission denied on serial port
```bash
# Add user to dialout group
sudo usermod -a -G dialout $USER

# Logout and login again
```

## OpenBCI GUI Issues

### Port not appearing in REFRESH LIST

1. Ensure rfcomm port exists: `ls /dev/rfcomm0`
2. Restart the OpenBCI GUI (Stop + Run in Processing)
3. Click REFRESH LIST again

### BOARD_NOT_READY_ERROR

- Ensure Potyplex EEG board is powered on (LED should be lit)
- Check Bluetooth connection is active
- Try disconnecting and reconnecting:
  ```bash
  sudo rfcomm release 0
  sudo rfcomm bind 0 0C:DC:7E:8E:30:8E
  ```

### USB Serial (CH340) not detected

1. Check if device is connected:
   ```bash
   lsusb | grep CH340
   ls /dev/ttyUSB*
   ```

2. Check kernel module:
   ```bash
   lsmod | grep ch341
   ```

3. If not loaded:
   ```bash
   sudo modprobe ch341
   ```

## System Requirements

- **OS**: Linux (tested on Ubuntu)
- **Processing IDE**: 4.x
- **Bluetooth**: bluez, rfcomm
- **User groups**: dialout

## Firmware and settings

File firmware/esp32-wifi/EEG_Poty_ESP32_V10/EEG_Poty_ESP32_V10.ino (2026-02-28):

// Potyplex EEG - WiFi UDP Access Point Version

#include <WiFi.h>
#include <WiFiUdp.h>
#include <SPI.h>
#include "EEG_Poty_ESP32_Library.h"
#include "EEG_Poty_ESP32_Library_Definitions.h"
#include "TestSignal.h"

#define LED_BUILTIN 2

// External WiFi status from library
extern bool wifiConnected;

//=============================================================================
// TEST SIGNAL CONFIGURATION
//=============================================================================
#define TEST_SIGNAL_ENABLED   true    // Set to false to disable test signal
#define TEST_SIGNAL_CHANNEL   7       // Channel 0-7 (channel 8 in 1-indexed)
#define TEST_SIGNAL_FREQ_HZ   10.0    // Frequency in Hz (0.1 to 50)
//=============================================================================

void setup() {
  // Bring up the OpenBCI Board (includes WiFi initialization)
  board.begin();
  board.setBoardMode(board.BOARD_MODE_POTYPLEX);
  board.useAccel(false);

  // Configure test signal generator
  #if TEST_SIGNAL_ENABLED
    testSignal.configure(TEST_SIGNAL_CHANNEL, TEST_SIGNAL_FREQ_HZ);
    testSignal.enable();
    Serial.println("===========================================");
    Serial.print("Test signal: CH");
    Serial.print(TEST_SIGNAL_CHANNEL + 1);  // 1-indexed for display
    Serial.print(" @ ");
    Serial.print(TEST_SIGNAL_FREQ_HZ);
    Serial.println(" Hz square wave");
    Serial.println("===========================================");
  #endif

  // LED indicates WiFi status
  if (wifiConnected) {
    // Blink 3 times to indicate success
    for (int i = 0; i < 3; i++) {
      digitalWrite(LED_BUILTIN, HIGH);
      delay(100);
      digitalWrite(LED_BUILTIN, LOW);
      delay(100);
    }
  } else {
    // Keep LED on to indicate WiFi error
    digitalWrite(LED_BUILTIN, HIGH);
  }
}

void loop() {
  if (board.streaming) {
    if (board.channelDataAvailable) {
      digitalWrite(LED_BUILTIN, HIGH);
      board.updateChannelData();            // Read from the ADS(s), store data, set flag to false
      digitalWrite(LED_BUILTIN, LOW);
      board.sendChannelData();              // Send that channel data via UDP
    }
  }
  // Check for incoming commands (via UDP or USB Serial)
  if (board.hasDataSerial()) board.processChar(board.getCharSerial());
  board.loop();
}

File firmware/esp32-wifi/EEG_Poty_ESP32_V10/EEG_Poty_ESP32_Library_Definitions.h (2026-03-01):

//
//Definitions_32.h
//
//
//  Created by Conor Russomanno, Luke Travis, and Joel Murphy. Summer 2013.
//	Modified by Joel Murphy, Summer 2014
//	Joel Added Daisy Functionality Fall 2014
//
//  Modified by George Nascimento, September 2020 to work on ESP32 boards

#ifndef _____EEG_Poty_ESP32_Library_Definitions_h
#define _____EEG_Poty_ESP32_Library_Definitions_h

//=============================================================================
// COMMUNICATION MODE: WiFi UDP Access Point
//=============================================================================
// Access Point Configuration
#define AP_SSID     "Potyplex-EEG"         // Network name created by ESP32
#define AP_PASSWORD "eeg12345"             // Password (min 8 chars, or "" for open)
#define AP_CHANNEL  1                       // WiFi channel (1-13)
#define AP_MAX_CONNECTIONS 2                // Max simultaneous clients

// UDP Port - ESP32 listens on this port, clients connect to it
#define UDP_PORT 12345

// Device name (for mDNS discovery)
#define DEVICE_NAME "potyplex-eeg"

// Client timeout: disconnect client if no command received in this time (ms)
// Set to 0 to disable timeout (streaming continues until 's' command)
#define CLIENT_TIMEOUT_MS 0

//=============================================================================
// DEBUG MODE
//=============================================================================
#define DEBUG 0  // if DEBUG==1 the data is streamed through USB serial for debugging

// SerialPort macro - for debug output only (data goes via UDP)
#if DEBUG == 1
  #define SerialPort Serial
#else
  #define SerialPort Serial  // Keep Serial for debug messages, UDP for data
#endif

//=============================================================================
// FIRMWARE INFO
//=============================================================================
#define boardID "Prototype V1"
#define firmware "v1.0-wifi"      // WiFi AP version

//specific for the MPU-6050
#define MPU6050_addr 0x68 

//specific for FireBeatle ESP32 board
#define DRDY_pin   26
#define RESET_pin  13
#define PWDN_pin   27
#define START_pin  25
#define SS_pin      5
#define MISO  19
#define MOSI  23
#define SCK   18



//SPI Command Definitions (pg. 35)
const byte spi_WAKEUP = 0b00000010;     // Wake-up from standby mode
const byte spi_STANDBY = 0b00000100;   // Enter Standby mode
const byte spi_RESET = 0b00000110;   // Reset the device
const byte spi_START = 0b00001000;   // Start and restart (synchronize) conversions
const byte spi_STOP = 0b00001010;   // Stop conversion
const byte spi_RDATAC = 0b00010000;   // Enable Read Data Continuous mode (default mode at power-up) 
const byte spi_SDATAC = 0b00010001;   // Stop Read Data Continuous mode
const byte spi_RDATA = 0b00010010;   // Read data by command; supports multiple read back


// Baud rates
#define OPENBCI_BAUD_RATE 115200
#define OPENBCI_BAUD_RATE_BLE 9600
#define OPENBCI_BAUD_RATE_MIN_NO_AVG 200000

// File transmissions
#define OPENBCI_BOP 'A' // Begining of stream packet

//PIN CONNECTIONS
#define ADS_DRDY 26          // ADS data ready pin
#define ADS_RST	13           // ADS reset pin
#define BOARD_ADS	5         // ADS chip select
#define LIS3DH_SS	1         // LIS3DH chip select
#define LIS3DH_DRDY 0	      // LIS3DH data ready pin
// #define WIFI_SS 13          // Wifi Chip Select
#define OPENBCI_PIN_LED 11
#define OPENBCI_PIN_PGC 12
// #define WIFI_RESET 18

#define OPENBCI_PIN_SERIAL1_TX 11
#define OPENBCI_PIN_SERIAL1_RX 12

//ADS1299 SPI Command Definition Byte Assignments
#define _WAKEUP 0x02 // Wake-up from standby mode
#define _STANDBY 0x04 // Enter Standby mode
#define _RESET 0x06 // Reset the device registers to default
#define _START 0x08 // Start and restart (synchronize) conversions
#define _STOP 0x0A // Stop conversion
#define _RDATAC 0x10 // Enable Read Data Continuous mode (default mode at power-up)
#define _SDATAC 0x11 // Stop Read Data Continuous mode
#define _RDATA 0x12 // Read data by command supports multiple read back

//ASD1299 Register Addresses
#define ADS_ID	0x3E	// product ID for ADS1299
#define ID_REG  0x00	// this register contains ADS_ID
#define CONFIG1 0x01
#define CONFIG2 0x02
#define CONFIG3 0x03
#define LOFF 0x04
#define CH1SET 0x05
#define CH2SET 0x06
#define CH3SET 0x07
#define CH4SET 0x08
#define CH5SET 0x09
#define CH6SET 0x0A
#define CH7SET 0x0B
#define CH8SET 0x0C
#define BIAS_SENSP 0x0D
#define BIAS_SENSN 0x0E
#define LOFF_SENSP 0x0F
#define LOFF_SENSN 0x10
#define LOFF_FLIP 0x11
#define LOFF_STATP 0x12
#define LOFF_STATN 0x13
#define GPIO 0x14
#define MISC1 0x15
#define MISC2 0x16
#define CONFIG4 0x17
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

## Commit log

2026-02-27 Reorganize project and add complete EEG system
    - Add ESP32 firmware (EEG_Poty_ESP32_V10) with Arduino libraries
    - Add PotyEEG v9 PCB files (schematic, board, BOM, Gerber)
    - Add ADS1299 datasheets
    - Add modified OpenBCI GUI with CH340/Bluetooth support
    - Add scripts: connect-bluetooth.sh, open-gui.sh
    - Add documentation and troubleshooting guide
    [PotyEEG_v9.brd, PotyEEG_v9.sch, PotyEEG_v9_BOM.xlsx]
2026-02-28 Add ESP32 WiFi Access Point firmware version
    - Add esp32-wifi firmware with UDP communication
    - ESP32 creates its own WiFi network (Access Point mode)
    - SSID: Potyplex-EEG, Password: eeg12345, IP: 192.168.4.1
    - Reorganize esp32 bluetooth firmware into project folder
    - Remove redundant local libraries (use Arduino IDE libraries)
2026-02-28 Add web viewer (FastAPI + React) and improve WiFi firmware
    Firmware changes:
    - Remove BLE code from esp32-wifi version
    - Fix 22-byte bug (now sends all 24 bytes for 8 channels)
    - Add test signal generator (square wave on configurable channel)
    Project restructure:
    - Rename software/ to software-processing/
    - Add software-web/ with FastAPI backend and React frontend
    Web viewer features:
    - FastAPI backend with UDP receiver and WebSocket broadcast
    - React frontend with Recharts for real-time EEG visualization
    - Service manager script (run.sh) for easy start/stop
    - Support for 8-channel display with channel selection
    Co-Authore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
2026-03-01 Fix WebSocket stability and improve UI layout
    Frontend fixes:
    - Remove useCallback dependency causing reconnection loop
    - Buffer data and update UI at 20 FPS instead of 250 Hz
    - Add proper cleanup on unmount
    - Use memo for EEGChart component
    Layout improvements:
    - 2 charts per row using CSS grid
    - GitHub-style dark theme
    - Better status indicators and LIVE badge
    - Improved button styling with icons
    Backend fixes:
    - Increase WebSocket timeout to 60s
    - Handle pong responses from client
    - Better error handling
2026-03-01 Fix streaming stability with batched WebSocket messages
    Backend:
    - Send samples in batches every 50ms (20 batches/sec)
    - Reduces WebSocket overhead from 250 to 20 messages/sec
    - Use shortened JSON keys (s, c, a) for less bandwidth
    - Simple buffer swap instead of deque processing
    Frontend:
    - Handle batch messages with multiple samples
    - Process all samples in batch at once
    This prevents event loop blocking and ensures continuous streaming.
2026-03-01 Add heartbeat to prevent ESP32 streaming timeout
    Root cause: ESP32 firmware stops streaming after 30s without
    receiving commands (CLIENT_TIMEOUT_MS in firmware)
    Solution: Backend sends 'b' command every 5 seconds while
    streaming is active and clients are connected
2026-03-01 Add keepalive, connection status and zoom controls
    - Keepalive every 25s (before ESP32 30s timeout)
    - Prevents streaming interruption
    - Connection status: ESP32 Conectado / Aguardando ESP32 / Desconectado
    - Only shows "ESP32 Conectado" when actually receiving data
    - Zoom controls per channel: Auto (A), +/- zoom, Reset (R)
    - Auto-zoom enabled by default
    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
2026-03-01 Remove keepalive, add system status panel and fix auto-zoom
    - Firmware: Disable client timeout (CLIENT_TIMEOUT_MS=0) so streaming
    continues until explicit stop command, eliminating keepalive artifacts
    - Backend: Remove proactive keepalive worker, add system event logging
    with /logs endpoint, improve debug output showing all 8 channels
    - Frontend: Add collapsible system status panel with connection status,
    sample count and event log; fix auto-zoom to ensure minimum visible
    range when channel values are constant or near-zero
    [EEG_Poty_ESP32_Library.cpp, EEG_Poty_ESP32_Library_Definitions.h]
2026-03-01 Add recordings tab with offline viewer and dark/light theme
    - New recording format: session folder with data.csv + metadata.json
    - Add periodic flush (every 250 samples) to prevent data loss
    - Add /record/marker endpoint for annotations
    - Add /recordings/{session_id} endpoint to fetch recording data
    - Add DELETE endpoint for recordings
    - Add tab navigation (Live / Recordings)
    - Add REC button with timer in Live tab
    - Create RecordingsTab component for offline viewing
    - Session list with date, duration, samples
    - Time-window navigation with zoom (5s/10s/30s/60s)
    - Channel selection and waveform display
    - Markers display, download and delete actions
    - Add dark/light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
2026-03-01 Add camera panel, improve UI layout, and add CLAUDE.md
    - Add USB camera support with WebSocket streaming (CameraPanel.jsx)
    - Move Samples/Rate/Target stats to System Status panel
    - Limit side column height to align with chart rows
    - Fix camera WebSocket reconnection loop (useEffect dependency bug)
    - Add CLAUDE.md for Claude Code guidance
2026-03-02 Improve recording controls, UI layout, and video playback
    - Move REC button to right side with Signal/Video checkboxes
    - Record only selected channels, lock selection during recording
    - Move channel selector to side panel below camera
    - Add System Console panel with connection status and event log
    - Add Quick Info panel with stats and indicators
    - Fix camera status callback to update parent component
    - Fix video checkbox enabling when camera is active
    - Fix recording loading for dynamic channel columns
    - Add video player to recordings tab with proper aspect ratio
    - Add badges for channel count and video in recordings list
2026-03-02 Improve recording logic, UI stability, and video playback
    - Remove grid background from EEG charts (live and recordings)
    - Fix ESP32 indicator to show stable text with pulsing dot only
    - Add smooth CSS transitions to prevent UI flickering
    - Separate camera and signal controls (independent start/stop)
    - Fix recording checkboxes to use streaming state (more stable)
    - Disable Stop buttons during active recording to prevent data loss
    - Add video conversion (AVI to MP4) for browser playback via ffmpeg
    - Support video-only or signals-only recording modes
    - Show video-only recordings correctly in recordings tab
2026-03-02 Add backend tests, record directly to MP4, update docs
    - Add 20 backend tests (packet parser, API endpoints, recording, WebSocket)
    - Record video directly to MP4 (mp4v codec) instead of AVI
    - Remove ffmpeg conversion dependency for video playback
    - Add test option (t) to run.sh menu
    - Update CLAUDE.md, README.md with current features and test instructions
